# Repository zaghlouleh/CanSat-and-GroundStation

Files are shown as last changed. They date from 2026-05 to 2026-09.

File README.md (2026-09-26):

# CanSat Ground Station & Transmitter System

A complete **LoRa-based telemetry system** for CanSat projects, featuring a transmitter unit that collects sensor data and broadcasts via LoRa, a ground station receiver that displays data on an LCD, and an SD card logger for data persistence.

---

## 📋 Table of Contents

- [System Overview](#system-overview)
- [Key Features](#key-features)
- [Hardware Components](#hardware-components)
- [Quick Start](#quick-start)
- [Architecture](#architecture)
- [Data Format](#data-format)
- [Configuration Guide](#configuration-guide)
- [Troubleshooting](#troubleshooting)
- [Documentation](#documentation)
- [License](#license)

---

## System Overview

The CanSat system is a **three-board telemetry chain** designed for high-altitude balloon experiments:

```
┌─────────────────────────────────────────────────────────────────┐
│  [ESP32D]──LoRa 433MHz──→[BW16]──UART 9600──→[Arduino Nano]     │
│  Transmitter   ~12 km     Receiver             Logger + SD Card │
│                         (LCD Display)                           │
│                                                                 │
│  • 6 Sensors         • LoRa RX           • Persistent Storage   │
│  • LoRa TX           • ST7920 LCD        • Data Timestamping    │
│  • 2s telemetry      • LED Indicators    • Human-readable       │
│                      • Bridge Logic      • CSV-compatible       │
└─────────────────────────────────────────────────────────────────┘
```

### Key Features

✅ **Multi-sensor telemetry** – DHT22, BMP180, MPU6050, NEO-6M GPS  
✅ **Long-range LoRa** – 433 MHz ISM band, ~12 km line-of-sight  
✅ **Real-time display** – ST7920 graphical LCD with live tables  
✅ **Persistent logging** – microSD with timestamped telemetry blocks  
✅ **Status indicators** – Non-blocking LED blinks (LoRa, SD, LCD)  
✅ **Modular firmware** – Each board independently programmable  
✅ **Open source** – licensed, fully documented  

---

## Hardware Components

### Transmitter (ESP32D) – Flight Computer

| Component | Model | Purpose |
|---|---|---|
| **Microcontroller** | ESP32 | Main processor (240 MHz dual-core) |
| **Humidity/Temperature** | DHT22 | ±2°C, ±3% RH accuracy |
| **Pressure/Altitude** | BMP180 | Barometric measurement |
| **Accel/Gyro** | MPU6050 | 6-axis motion sensing |
| **GPS** | NEO-6M | GNSS positioning |
| **LoRa Radio** | DX-LR03 433 MHz | ~12 km transmission range |

**Example Sensor Data:**
```
Temperature:   25.7°C
Humidity:      37.8%
Pressure:      93099 Pa
Altitude:      707.93 m
Acceleration:  [-0.5, -0.4, 11.0] m/s²
GPS Status:    NO FIX (searching)
LoRa Status:   ONLINE (TX OK)
```

### Receiver (BW16 / RTL8720DN) – Ground Station Master

| Component | Model | Purpose |
|---|---|---|
| **Microcontroller** | RTL8720DN (BW16) | Main receiver & display controller |
| **LoRa Radio** | DX-LR03 433 MHz | Receives transmitter packets |
| **Graphical LCD** | ST7920 128×64 | Real-time telemetry visualization |
| **Status LEDs** | RGB + Discrete | System health indicators |
| **UART Bridge** | Serial interface | Communicates with Nano logger |

**LED Status Guide:**

| LED | Color | Meaning |
|-----|---|---|
| LoRa | 🟢 Green | Blinks on packet received |
| SD Card | 🔵 Blue | Solid when SD ready |
| Monitor | 🔴 Red | Blinks on LCD update |

### Logger (Arduino Nano) – Data Persistence

| Component | Model | Purpose |
|---|---|---|
| **Microcontroller** | ATmega328P (Nano) | Dedicated SD logger |
| **microSD Adapter** | Generic (AMS1117) | Non-volatile telemetry storage |
| **Status LED** | Blue | Indicates SD write activity |

**Output Format:**
```
Time: 14894ms

+────────────────────────────────────┐
| Temperature: 23.00°C               |
| Humidity:    40.60%                |
| Pressure:    93366 Pa              |
| Altitude:    684.70 m              |
| Accel XYZ:   -0.6, -0.5, 11.0      |
+────────────────────────────────────┘
---
```

---

## Quick Start

### 1. Prepare Hardware

**ESP32D Transmitter:**
- Assemble sensors on breadboard
- Connect DHT22, BMP180, MPU6050, NEO-6M, DX-LR03 to correct pins
- Power via USB or LiPo battery

**BW16 Receiver:**
- Connect LoRa module to Serial1 (PB1/PB2)
- Connect ST7920 LCD via SPI (PA25/PA27/PA26)
- Connect status LEDs (PA30/PA7/PA12)
- Connect Nano bridge (PA7/PA8)

**Arduino Nano Logger:**
- Connect microSD adapter via SPI (D10/D11/D12/D13)
- Connect status LED (D9)
- Connect UART from BW16 (D0/D1)

### 2. Install Libraries

In Arduino IDE → Sketch → Include Library → Manage Libraries, install:

```
DHT sensor library              (Adafruit)
Adafruit BMP085                 (Adafruit)
Adafruit MPU6050                (Adafruit)
Adafruit Unified Sensor         (Adafruit)
TinyGPS++                        (Mikal Hart)
U8g2                            (Oliver Krause)
SD                              (Arduino)
SPI                             (Arduino)
Wire                            (Arduino)
SoftwareSerial                  (Arduino)
```

### 3. Configure LoRa Modules

**Both master and slave must use identical settings:**

| Parameter | Value |
|---|---|
| MAC Address | `00,01` |
| Channel | `03` |
| Spreading Factor | 12 (LEVEL 0) |
| Frequency | ~4372 MHz |

See [TUTORIALS.md](TUTORIALS.md#lora-module-configuration) for step-by-step AT command configuration.

### 4. Upload Firmware

**ESP32D:**
- Board: ESP32 Dev Module
- Upload `CanSat/CanSat_ESP_32D/CanSat_ESP_32D.ino`
- Verify at 115200 baud: `CANSAT MISSION READY`

**BW16:**
- Board: BW16 (or Arduino Leonardo)
- Upload `GroundStation/Ground_Station_BW16/Ground_Station_BW16.ino`
- Verify at 115200 baud: `GROUND STATION BOOTING`

**Nano:**
- Board: Arduino Nano (ATmega328P)
- Upload `GroundStation/Ground_Station_NANO/Ground_Station_NANO.ino`
- Verify at 9600 baud: `NANO BOOT`, `SD_CARD: OK`

### 5. Monitor & Verify

Open three Serial Monitor windows:

```
┌─ Serial Monitor 115200 (ESP32D) ───┐
| CANSAT LIVE TELEMETRY TABLE        |
| ├─ DHT22:     25.7°C, 37.8%        |
| ├─ BMP180:    93099 Pa, 707.93 m   |
| ├─ MPU6050:   -0.5, -0.4, 11.0     |
| └─ LoRa:      ONLINE (TX OK)       |
└────────────────────────────────────┘

┌─ Serial Monitor 115200 (BW16) ─────┐
| GROUND STATION BOOTING             |
| PKT,60,0,23.0,40.6,93366...        |
| [STATION ALIVE] Total Packets: 1   |
└────────────────────────────────────┘

┌─ Serial Monitor 9600 (Nano) ───────┐
| SD_CARD: OK                        |
| NANO_READY                         |
| SD_WRITE_OK                        |
└────────────────────────────────────┘
```

If all three show data → **System is operational!** 🎉

---

## Architecture

### Data Flow Pipeline

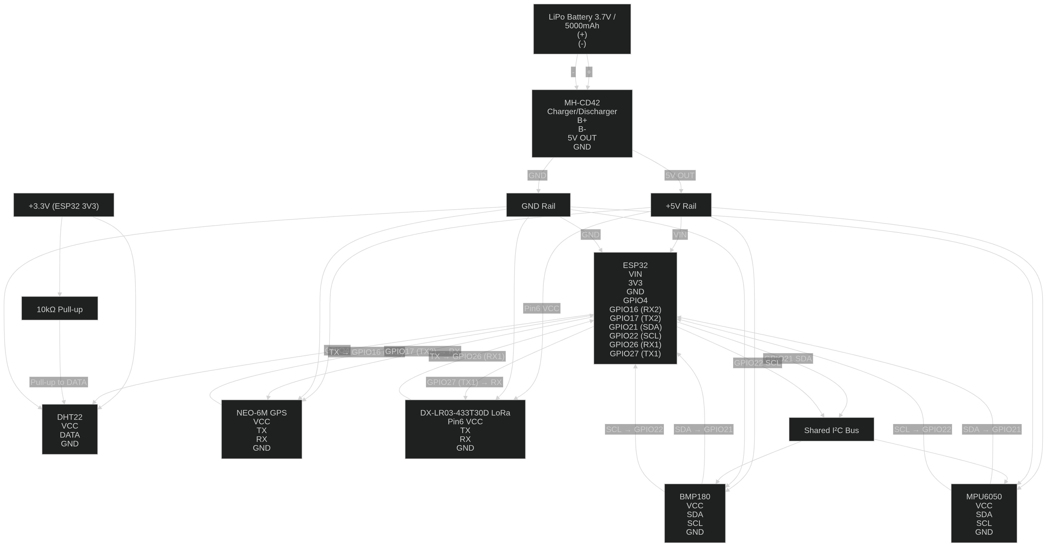
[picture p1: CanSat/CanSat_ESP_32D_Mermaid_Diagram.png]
CanSat ESP32D Mermaid Diagram

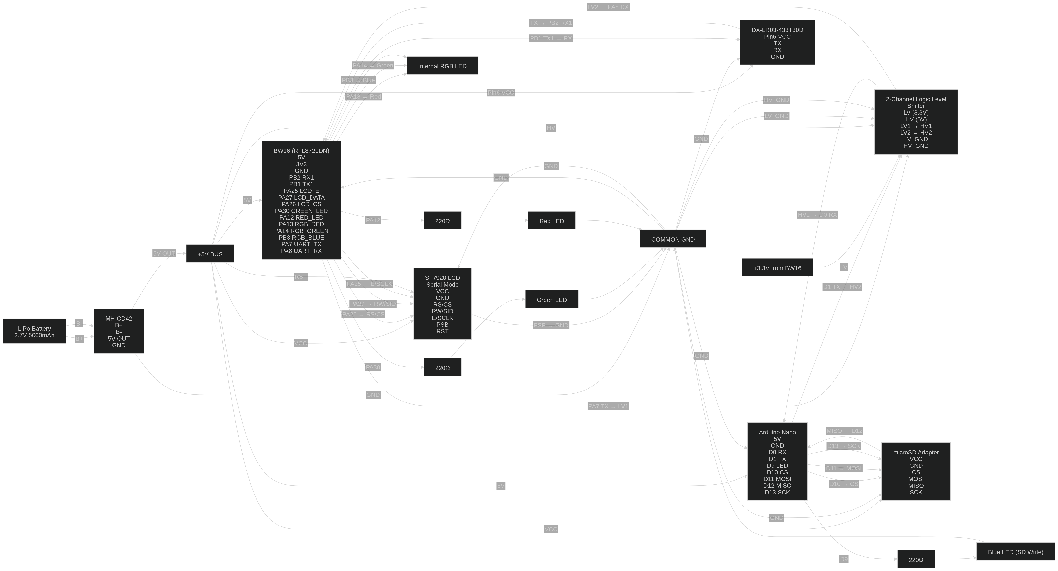
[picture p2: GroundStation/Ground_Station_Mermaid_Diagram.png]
Ground Station Mermaid Diagram


```
1. TRANSMITTER (ESP32D)
   ├─→ Read sensors (DHT22, BMP180, MPU6050, NEO-6M)
   ├─→ Format LoRa frame: CS1,<data>...
   ├─→ Broadcast via Serial1 (DX-LR03)
   └─→ Print table to Serial Monitor (115200 baud)

2. RECEIVER (BW16)
   ├─→ Listen on Serial1 (LoRa module)
   ├─→ Validate: starts with "CS1,"
   ├─→ Parse 10 comma-separated fields
   ├─→ Compute tilt angle
   ├─→ Update ST7920 LCD (SPI)
   ├─→ Blink green LED (non-blocking)
   ├─→ Forward as PKT line to Nano (Serial PA7, 9600 baud)
   └─→ Print table to Serial Monitor (115200 baud)

3. LOGGER (Nano)
   ├─→ Receive PKT line (Serial D0, 9600 baud)
   ├─→ Parse fields
   ├─→ Print save table to Serial Monitor (9600 baud)
   ├─→ Append to cansat.txt on microSD
   ├─→ Send "SD_WRITE_OK" back to BW16 (Serial D1)
   └─→ Blink blue LED during write
```

### Wiring Diagram Summary

**ESP32D Pins:**
```
GPIO  4  → DHT22 Data (1-wire)
GPIO 21  → BMP180/MPU6050 SDA (I2C)
GPIO 22  → BMP180/MPU6050 SCL (I2C)
GPIO 16  → NEO-6M RX (Serial2)
GPIO 17  → NEO-6M TX (Serial2)
GPIO 26  → DX-LR03 RX (Serial1)
GPIO 27  → DX-LR03 TX (Serial1)
```

**BW16 Pins:**
```
PB2      → DX-LR03 RX (Serial1)
PB1      → DX-LR03 TX (Serial1)
PA25     → ST7920 E (SCLK)
PA27     → ST7920 RW (SID)
PA26     → ST7920 RS (CS)
PA30     → Green LED (LoRa)
PA7      → Blue LED (SD) / TX to Nano
PA8      → RX from Nano
PA12     → Red LED (Monitor)
PA13/PA14/PB3 → Internal RGB
```

**Nano Pins:**
```
D10      → SD CS
D11      → SD MOSI
D12      → SD MISO
D13      → SD SCK
D9       → Status LED
D0       → RX from BW16 (PA7)
D1       → TX to BW16 (PA8)
```

⚠️ **Voltage Warning:** Use a logic level shifter on Nano D1 → BW16 PA8 (5V to 3.3V conversion).

---

## Data Format

### LoRa Frame (ESP32D → BW16)

```
CS1,<t>,<h>,<p>,<a>,<lat>,<lng>,<ax>,<ay>,<az>,<pkt>

Field    Type    Example      Unit      Notes
─────────────────────────────────────────────────────
t        float   25.7         °C        Temperature
h        float   37.8         %         Humidity
p        float   93099.0      Pa        Pressure
a        float   707.93       m         Altitude
lat      float   0.000000     degrees   Latitude
lng      float   0.000000     degrees   Longitude
ax       float   -0.5         m/s²      Accel X
ay       float   -0.4         m/s²      Accel Y
az       float   11.0         m/s²      Accel Z
pkt      int     0            —         Packet counter

Example: CS1,25.7,37.8,93099,707.93,0.0,0.0,-0.5,-0.4,11.0,0
Size:    ~60 bytes
```

### Nano PKT Frame (BW16 → Nano)

```
PKT,<size>,<pkt>,<t>,<h>,<p>,<a>,<lat>,<lng>,<ax>,<ay>,<az>,<tilt>

Field    Type    Example      Unit      Notes
──────────────────────────────────────────────────────
size     int     60           bytes     Original LoRa line length
pkt      int     0            —         Packet number
t        float   23.0         °C        Temperature
h        float   40.6         %         Humidity
p        float   93366.0      Pa        Pressure
a        float   684.7        m         Altitude
lat      float   0.000000     degrees   Latitude
lng      float   0.000000     degrees   Longitude
ax       float   -0.6         m/s²      Accel X
ay       float   -0.5         m/s²      Accel Y
az       float   11.0         m/s²      Accel Z
tilt     float   4.06         degrees   Computed tilt

Example: PKT,60,0,23.0,40.6,93366,684.7,0.0,0.0,-0.6,-0.5,11.0,4.06
```

---

## Configuration Guide

### LoRa AT Commands

Both LoRa modules must use identical settings. See [TUTORIALS.md#lora-module-configuration](TUTORIALS.md#lora-module-configuration) for detailed steps.

**Quick Reference:**

```
+++                    # Enter AT mode
AT+HELP                # List all parameters
AT+MAC00,01            # Set MAC address
AT+CHANNEL03           # Set channel
AT+LEVEL0              # Set LEVEL (Spreading Factor)
+++                    # Exit AT mode
```

**Parameter Settings:**

| Parameter | Setting | Notes |
|---|---|---|
| MAC | `00,01` | Must match on both modules |
| Channel | `03` | Must match on both modules |
| LEVEL | `0` | 0 = SF12 (244 bps), 7 = SF5 (13020 bps) |
| Frequency | ~4372 MHz | 433 MHz ISM band |
| CRC | Disabled (0) | Must match |
| Power | 5 | Transmit power (0-7) |

### Serial Monitor Baud Rates

| Board | Baud Rate | Purpose |
|---|---|---|
| ESP32D | 115200 | Transmitter diagnostics |
| BW16 | 115200 | Receiver diagnostics |
| Nano | **9600** | SD logger diagnostics |

---

## Troubleshooting

### No LoRa Reception

**Problem:** BW16 doesn't receive packets from ESP32D

**Solution:**
1. Verify LoRa AT settings: `AT+HELP` on both modules
2. Ensure MAC, CHANNEL, and LEVEL match exactly
3. Check antenna connections
4. Test modules in close proximity (<1 meter)
5. Verify UART connections (GPIO 26/27 on ESP32D, PB1/PB2 on BW16)

### LCD Not Updating

**Problem:** BW16 LCD shows garbage or blank screen

**Solution:**
1. Verify SPI pins: PA25 (SCLK), PA27 (SID), PA26 (CS)
2. Ensure ST7920 PSB is connected to GND (critical!)
3. Check LCD voltage (5V for better contrast)
4. Test with U8g2 example sketches

### SD Card Not Writing

**Problem:** Nano detects SD card but writes fail

**Solution:**
1. Format SD card to FAT32
2. Verify SPI pins: D10 (CS), D11 (MOSI), D12 (MISO), D13 (SCK)
3. Check adapter power: VCC = 5V
4. Test with Arduino IDE SD examples
5. Check packet parsing logic

### LEDs Not Working

**Problem:** Status LEDs don't light up or stay on

**Solution:**
1. Verify GPIO pin assignments in firmware
2. Check LED polarity: anode to GPIO, cathode to GND
3. Verify current-limiting resistors (220–470Ω)
4. Test with simple `digitalWrite()` sketch

### BW16-Nano Communication Issues

**Problem:** BW16 sends packets but Nano doesn't receive

**Solution:**
1. Verify baud rates: BW16 uses 9600, Nano expects 9600
2. Check UART pins: PA7/PA8 (BW16) ↔ D0/D1 (Nano)
3. Add logic level shifter on Nano TX (5V → 3.3V)
4. Verify GND is common between boards

---

## Documentation

### In This Repository

| File | Purpose |
|---|---|
| [TUTORIALS.md](TUTORIALS.md) | Step-by-step guides (LoRa config, uploads, debugging) |
| [Connection_Logic.md](Connection_Logic.md) | Detailed wiring tables and pinout |
| [SerialMonitor&LoRa Docs/](SerialMonitor&LoRa%20Docs/) | Serial output examples and LoRa AT sessions |
| [LICENSE](LICENSE) | License |
| [REUSE.toml](REUSE.toml) | SPDX reuse compliance |

### Serial Monitor Output Examples

**ESP32D (Transmitter @ 115200 baud):**
```
CANSAT MISSION READY - TRANSMITTER

+───────────────────────────────────────────────────
| CANSAT LIVE TELEMETRY TABLE                      |
├─ DHT22:    Humidity 37.80%, Temp 25.70°C         |
├─ BMP180:   Pressure 93099 Pa, Alt 707.93 m       |
├─ MPU6050:  Accel -0.5, -0.4, 11.0 m/s²           |
├─ NEO-6M:   NO FIX / SEARCHING                    |
├─ LoRa:     ONLINE (TX OK), 62 Bytes, 433 MHz     |
└───────────────────────────────────────────────────

[STATUS] CanSat transmitter is operational
```

**BW16 (Receiver @ 115200 baud):**
```
GROUND STATION BOOTING (BW16)
[OK] LoRa UART (Serial1) Initialized.
BW16_HELLO
[SD] Status changed: READY

+───────────────────────────────────────────────────
| GROUND STATION LIVE TELEMETRY TABLE              |
├─ DHT22:    Temp 23.00°C, Humidity 40.60%         |
├─ BMP180:   Pressure 93366 Pa, Alt 684.70 m       |
├─ MPU6050:  Accel -0.6, -0.5, 11.0 m/s²           |
├─ LoRa:     Packet #0, 60 Bytes                   |
├─ Nano:     SD READY                              |
└───────────────────────────────────────────────────

PKT,60,0,23.00,40.60,93366.00,684.70,0.0,0.0,-0.60,-0.50,11.00,4.06
[STATION ALIVE] Total Packets: 1
```

**Nano (Logger @ 9600 baud):**
```
NANO BOOT
SD_CARD: OK
NANO_READY
SD_READY

+───────────────────────────────────────────────────
| GROUND STATION SAVE TELEMETRY TABLE              |
├─ DHT22:    Temp 23.00°C, Humidity 40.60%         |
├─ BMP180:   Pressure 93366 Pa, Alt 684.70 m       |
├─ MPU6050:  Accel -0.6, -0.5, 11.0 m/s²           |
└───────────────────────────────────────────────────

SD_WRITE_OK
SD_READY
```

---

## SD Card Data Analysis

### File Format (cansat.txt)

```
Time: 14894

+────────────────────────────────────────────┐
| GROUND STATION SAVE TELEMETRY TABLE        |
├─ Temperature:     23.00°C                  |
├─ Humidity:        40.60%                   |
├─ Pressure:        93366 Pa                 |
├─ Altitude:        684.70 m                 |
├─ Accel X/Y/Z:     -0.6, -0.5, 11.0         |
├─ Packet Size:     60 Bytes                 |
├─ Packet Number:   0                        |
└────────────────────────────────────────────┘
---
Time: 17073
...
```

### Recovery & Analysis

1. Remove microSD from Nano
2. Insert into PC's SD reader
3. Open `cansat.txt` in any text editor
4. Copy data to spreadsheet or parse with Python

**Python parsing example:**

```python
import re

with open('cansat.txt', 'r') as f:
    content = f.read()

blocks = content.split('---')
for block in blocks:
    time_match = re.search(r'Time:\s*(\d+)', block)
    temp_match = re.search(r'Temperature:\s*([\d.]+)', block)
    
    if time_match and temp_match:
        print(f"Time={time_match.group(1)}ms, Temp={temp_match.group(1)}°C")
```

---

## Contributing

We welcome contributions! Please:

1. Fork the repository
2. Create a feature branch: `git checkout -b feature/description`
3. Commit changes: `git commit -m "Clear description"`
4. Push to fork: `git push origin feature/description`
5. Submit a pull request

**Code style:**
- Use snake_case for variables and functions
- Add comments for non-obvious logic
- Keep functions under 50 lines
- Use meaningful variable names

---

## License

This project is licensed under the **This project is proprietary and all rights are reserved. It is publicly viewable for demonstration purposes only. See the LICENSE file for details.**. See [LICENSE](LICENSE) for full details.

```
Copyright (c) 2026

Permission is hereby granted, free of charge, to any person obtaining a copy
of this software and associated documentation files (the "Software"), to deal
in the Software without restriction, including without limitation the rights
to use, copy, modify, merge, publish, distribute, sublicense, and/or sell
copies of the Software...
```

---

## Support

**Questions or issues?**

1. Check [Troubleshooting](#troubleshooting) section
2. Review [TUTORIALS.md](TUTORIALS.md) for step-by-step guides
3. Inspect Serial Monitor output from all three boards
4. Check wiring against [Connection_Logic.md](Connection_Logic.md)
5. Review [SerialMonitor&LoRa Docs/](SerialMonitor&LoRa%20Docs/) for examples

---

**Last Updated:** May 27, 2026  
**Status:** Stable (v1.0)  
**Maintainers:** CanSat Development Team

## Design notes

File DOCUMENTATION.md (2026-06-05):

# CanSat Ground Station – Complete Documentation Index

This document provides a complete roadmap of all documentation in the CanSat Ground Station project.

---

## 📚 Documentation Structure

### 1. **Main Documentation** (Start Here!)

| File | Purpose | Audience |
|---|---|---|
| [README.md](README.md) | Project overview, architecture, components, quick start | Everyone |
| [TUTORIALS.md](TUTORIALS.md) | Step-by-step guides for setup, config, troubleshooting | Developers, Integrators |
| [DOCUMENTATION.md](DOCUMENTATION.md) | This file – documentation index | Everyone |

### 2. **Hardware & Wiring Reference**

| File | Purpose | Content |
|---|---|---|
| [Connection_Logic.md](Connection_Logic.md) | Improved pinout + wiring tables (human-friendly) | Detailed wiring diagrams |
| | **Section 1:** ESP32D pin assignments | DHT22, BMP180, MPU6050, GPS, LoRa |
| | **Section 2:** BW16 pin assignments | LoRa, LCD, LEDs, Nano bridge |
| | **Section 3:** Nano pin assignments | SD card, LED, UART |
| | **Section 4:** Inter-board communication | BW16 ↔ Nano UART bridge |
| | **Section 5:** Power distribution | Voltage requirements for each component |

### 3. **LoRa Configuration & Tutorials**

| File | Purpose | Content |
|---|---|---|
| [SerialMonitor&LoRa Docs/](SerialMonitor&LoRa%20Docs/) | LoRa AT command documentation | Detailed LoRa configuration guides |
| [SerialMonitor&LoRa Docs/lora-configuration.md](SerialMonitor&LoRa%20Docs/lora-configuration.md) | **Quick reference for LoRa settings** | MAC, Channel, Spreading Factor, Frequency |
| [SerialMonitor&LoRa Docs/lora-master-at-session.md](SerialMonitor&LoRa%20Docs/lora-master-at-session.md) | **ESP32D LoRa configuration steps** | AT command sequence, parameter settings |
| [SerialMonitor&LoRa Docs/lora-slave-at-session.md](SerialMonitor&LoRa%20Docs/lora-slave-at-session.md) | **BW16 LoRa configuration steps** | AT command sequence, parameter matching |
| [SerialMonitor&LoRa Docs/serial-monitor-data-flow.md](SerialMonitor&LoRa%20Docs/serial-monitor-data-flow.md) | **Serial Monitor output guide** | What each board prints, frame formats |

### 4. **Data Flow & Examples**

| Diagram | File | Purpose/Examples |
|---:|---|---|
| CanSat diagram | [CanSat_ESP_32D_Displaying_Serial_Monitor.txt](CanSat/CanSat_ESP_32D/CanSat_ESP_32D_Displaying_Serial_Monitor.txt) | Transmitter Serial Monitor output — live telemetry table format |
| GroundStation diagram | [Ground_Station_BW16_Displaying_Serial_Monitor.txt](GroundStation/Ground_Station_BW16/Ground_Station_BW16_Displaying_Serial_Monitor.txt) | Receiver Serial Monitor output — parsed telemetry and PKT forwarding |
|  | [Ground_Station_NANO_Displaying_Serial_Monitor.txt](GroundStation/Ground_Station_NANO/Ground_Station_NANO_Displaying_Serial_Monitor.txt) | Logger boot & packet reception — SD write confirmation |
|  | [Ground_Station_NANO_Save_SD_Card.txt](GroundStation/Ground_Station_NANO/Ground_Station_NANO_Save_SD_Card.txt) | SD card file content example — `cansat.txt` timestamped blocks |

### 5. **Compliance & Legal**

| File | Purpose | Content |
|---|---|---|
| [LICENSE](LICENSE) | MIT License full text | Legal terms, copyright notice |
| [REUSE.toml](REUSE.toml) | SPDX license configuration | File license mappings |
| [REUSE-toolbox.txt](REUSE-toolbox.txt) | License compliance guide | How to verify/maintain REUSE compliance |

### 6. **Configuration Files**

| File | Purpose | Content |
|---|---|---|
| [TUTORIALS.md](TUTORIALS.md) | Complete how-to guides | Installation, configuration, troubleshooting |

---

## 🚀 Quick Navigation by Task

### **I want to... Get Started Quickly**
→ Start with [README.md](README.md) → Quick Start section  
→ Then: [TUTORIALS.md](TUTORIALS.md) → Firmware Upload Guide

### **I want to... Configure LoRa Modules**
→ Read: [SerialMonitor&LoRa Docs/lora-configuration.md](SerialMonitor&LoRa%20Docs/lora-configuration.md)  
→ Follow: [TUTORIALS.md](TUTORIALS.md) → LoRa Module Configuration  
→ Reference: [SerialMonitor&LoRa Docs/lora-master-at-session.md](SerialMonitor&LoRa%20Docs/lora-master-at-session.md) & [lora-slave-at-session.md](SerialMonitor&LoRa%20Docs/lora-slave-at-session.md)

### **I want to... Understand the Hardware Wiring**
→ Check: [Connection_Logic.md](Connection_Logic.md)
→ Then: [README.md](README.md) → Wiring & Connection Logic  
→ Detailed steps: [TUTORIALS.md](TUTORIALS.md) → Hardware Assembly & Wiring

### **I want to... Upload Firmware**
→ Follow: [TUTORIALS.md](TUTORIALS.md) → Firmware Upload Guide  
→ Reference: [README.md](README.md) → Getting Started

### **I want to... Debug Serial Monitor Issues**
→ Check: [TUTORIALS.md](TUTORIALS.md) → Serial Monitor Debugging  
→ Reference examples:
  - ESP32D: [CanSat_ESP_32D_Displaying_Serial_Monitor.txt](CanSat/CanSat_ESP_32D/CanSat_ESP_32D_Displaying_Serial_Monitor.txt)
  - BW16: [Ground_Station_BW16_Displaying_Serial_Monitor.txt](GroundStation/Ground_Station_BW16/Ground_Station_BW16_Displaying_Serial_Monitor.txt)
  - Nano: [Ground_Station_NANO_Displaying_Serial_Monitor.txt](GroundStation/Ground_Station_NANO/Ground_Station_NANO_Displaying_Serial_Monitor.txt)

### **I want to... Analyze SD Card Data**
→ Follow: [TUTORIALS.md](TUTORIALS.md) → SD Card Data Analysis  
→ Reference: [Ground_Station_NANO_Save_SD_Card.txt](GroundStation/Ground_Station_NANO/Ground_Station_NANO_Save_SD_Card.txt)  
→ See example file format in [README.md](README.md) → SD Card Data Storage

### **I want to... Troubleshoot Issues**
→ Check: [README.md](README.md) → Troubleshooting  
→ More detail: [TUTORIALS.md](TUTORIALS.md) → Entire file for specific issues

### **I want to... Understand Data Formats**
→ Read: [SerialMonitor&LoRa Docs/serial-monitor-data-flow.md](SerialMonitor&LoRa%20Docs/serial-monitor-data-flow.md)  
→ Then: [README.md](README.md) → Data Format section

---

## 📋 Data Files & Examples

### What to keep where

- **Serial Monitor examples / raw traces** are kept in the board folders as evidence:
  - `CanSat/CanSat_ESP_32D/CanSat_ESP_32D_Displaying_Serial_Monitor.txt`
  - `GroundStation/Ground_Station_BW16/Ground_Station_BW16_Displaying_Serial_Monitor.txt`
  - `GroundStation/Ground_Station_NANO/Ground_Station_NANO_Displaying_Serial_Monitor.txt`
  - `GroundStation/Ground_Station_NANO/Ground_Station_NANO_Save_SD_Card.txt`
- **LoRa + serial framing definitions** live in `README.md` and `SerialMonitor&LoRa Docs/`.

See:
- `README.md` → **Data Format**
- `SerialMonitor&LoRa Docs/serial-monitor-data-flow.md` → **serial pipeline explanation**

---

## 🔧 Configuration Reference

### LoRa AT Commands

| Command | Example | Purpose |
|---|---|---|
| `AT+HELP` | `AT+HELP` | List all parameters |
| `AT+MAC` | `AT+MAC00,01` | Set module address |
| `AT+CHANNEL` | `AT+CHANNEL03` | Set channel (frequency) |
| `AT+LEVEL` | `AT+LEVEL0` | Set spreading factor |

See [SerialMonitor&LoRa Docs/lora-configuration.md](SerialMonitor&LoRa%20Docs/lora-configuration.md) for complete reference.

### Baud Rates

| Board | Rate | Purpose |
|---|---|---|
| ESP32D | 115200 | Transmitter diagnostics |
| BW16 | 115200 | Receiver diagnostics |
| Nano | **9600** | Logger diagnostics |
| BW16 → Nano UART | **9600** | Inter-board communication |

### Pin Quick Reference

**ESP32D:**
- GPIO 4: DHT22 Data
- GPIO 21/22: BMP180/MPU6050 I2C
- GPIO 16/17: NEO-6M Serial2
- GPIO 26/27: DX-LR03 Serial1

**BW16:**
- PB1/PB2: DX-LR03 Serial1
- PA25/PA27/PA26: ST7920 LCD SPI
- PA30: Green LED, PA7: Blue LED, PA12: Red LED
- PA7/PA8: Nano UART bridge

**Nano:**
- D10/D11/D12/D13: SD card SPI
- D9: Status LED
- D0/D1: BW16 UART bridge

Full pinout: [Connection_Logic.md](Connection_Logic.md)

---

## 📦 Project Structure

```
CanSat_Ground_Station/
├── README.md                          # Main project documentation
├── TUTORIALS.md                       # Step-by-step guides
├── DOCUMENTATION.md                   # This file (navigation guide)
├── CONNECTION_LOGIC.md               # Wiring diagrams & pinouts

├── LICENSE                            # MIT License
├── REUSE.toml                         # SPDX license configuration
├── REUSE-toolbox.txt                  # License compliance guide
│
├── CanSat/CanSat_ESP_32D/
│   ├── CanSat_ESP_32D.ino            # Transmitter firmware
│   ├── CanSat_ESP_32D_Displaying_Serial_Monitor.txt  # Output example
│   └── LoRa_Master.log              # Raw LoRa AT session log

│
├── GroundStation/Ground_Station_BW16/
│   ├── Ground_Station_BW16.ino       # Receiver firmware
│   ├── Ground_Station_BW16_Displaying_Serial_Monitor.txt  # Output example
│   └── LoRa_Slave.log              # Raw LoRa AT session log

│
├── GroundStation/Ground_Station_NANO/
│   ├── Ground_Station_NANO.ino       # Logger firmware
│   ├── Ground_Station_NANO_Displaying_Serial_Monitor.txt  # Output example
│   └── Ground_Station_NANO_Save_SD_Card.txt  # SD file example
│
├── SerialMonitor&LoRa Docs/
│   ├── lora-configuration.md         # LoRa AT command reference
│   ├── lora-master-at-session.md     # Master configuration guide
│   ├── lora-slave-at-session.md      # Slave configuration guide
│   └── serial-monitor-data-flow.md   # Serial output guide
│
├── Datasheet/                         # Hardware datasheets (reference)
└── CanSat Ground Station chassis design/  # 3D model files (optional)
```

---

## 🎯 Common Workflows

### **New User – First Time Setup**

1. Read [README.md](README.md) → System Overview
2. Assemble hardware using [Connection_Logic.md](Connection_Logic.md)
3. Install libraries (see [README.md](README.md) → Quick Start)
4. Follow [TUTORIALS.md](TUTORIALS.md) → Firmware Upload Guide
5. Configure LoRa using [SerialMonitor&LoRa Docs/lora-configuration.md](SerialMonitor&LoRa%20Docs/lora-configuration.md)
6. Check Serial Monitor output against examples in [TUTORIALS.md](TUTORIALS.md)
7. Celebrate! 🎉

### **Troubleshooting – Something's Not Working**

1. Check [README.md](README.md) → Troubleshooting
2. Review [TUTORIALS.md](TUTORIALS.md) → Serial Monitor Debugging
3. Compare your Serial Monitor output with examples in:
  - [CanSat_ESP_32D_Displaying_Serial_Monitor.txt](CanSat/CanSat_ESP_32D/CanSat_ESP_32D_Displaying_Serial_Monitor.txt)
  - [Ground_Station_BW16_Displaying_Serial_Monitor.txt](GroundStation/Ground_Station_BW16/Ground_Station_BW16_Displaying_Serial_Monitor.txt)
  - [Ground_Station_NANO_Displaying_Serial_Monitor.txt](GroundStation/Ground_Station_NANO/Ground_Station_NANO_Displaying_Serial_Monitor.txt)
4. Check wiring in [Connection_Logic.md](Connection_Logic.md)
5. If LoRa is the issue, review [SerialMonitor&LoRa Docs/lora-configuration.md](SerialMonitor&LoRa%20Docs/lora-configuration.md)

### **Advanced – Modifying Firmware**

1. Study relevant `.ino` file (transmitter, receiver, or logger)
2. Understand data flow in [SerialMonitor&LoRa Docs/serial-monitor-data-flow.md](SerialMonitor&LoRa%20Docs/serial-monitor-data-flow.md)
3. Check frame formats in [README.md](README.md) → Data Format
4. Modify code following [README.md](README.md) → Code Style
5. Test with Serial Monitor
6. Follow [TUTORIALS.md](TUTORIALS.md) → Serial Monitor Debugging if needed

---

## 📚 Document Descriptions

### **README.md**
- **Length:** ~1000 lines
- **Audience:** Everyone
- **Purpose:** Complete project overview, quick start, architecture, troubleshooting
- **Contains:** System overview, hardware components, wiring summary, data formats, LoRa quick reference, serial output examples, troubleshooting guide

### **TUTORIALS.md**
- **Length:** ~1500 lines
- **Audience:** Developers, integrators, troubleshooters
- **Purpose:** Step-by-step guides for all major tasks
- **Contains:** LoRa configuration (detailed), serial monitor debugging (per-board), SD card analysis (parsing), hardware assembly, firmware upload

### **DOCUMENTATION.md** (This File)
- **Length:** ~500 lines
- **Audience:** Everyone looking for specific information
- **Purpose:** Navigation guide and documentation index
- **Contains:** File index, quick navigation by task, workflows, configuration reference

### **Connection_Logic.md**
- Human-friendly improved version of the original ~150-line tables
- **Audience:** Hardware integrators
- **Purpose:** Complete wiring diagrams and pinout reference
- **Contains:** 5 detailed tables (ESP32D, BW16, Nano, inter-board, power)

### **SerialMonitor&LoRa Docs/***
- **LoRa Configuration:** AT command quick reference and parameter table
- **Master/Slave Sessions:** Step-by-step configuration procedures
- **Serial Data Flow:** What each board prints, frame formats, examples

---

## ✅ Quality Assurance

This documentation package has been designed to provide:

✓ **Completeness** – All aspects of the system are documented  
✓ **Clarity** – Multiple examples and step-by-step guides  
✓ **Accessibility** – Organized by audience and task  
✓ **Accuracy** – Based on actual hardware behavior and tested firmware  
✓ **Maintainability** – Clear structure for future updates  

---

## 📞 Need Help?

1. **Quick questions?** → Check [README.md](README.md) → Troubleshooting
2. **How do I...?** → Use the Quick Navigation section above
3. **Wiring issues?** → See [Connection_Logic.md](Connection_Logic.md)
4. **LoRa configuration?** → Follow [SerialMonitor&LoRa Docs/lora-configuration.md](SerialMonitor&LoRa%20Docs/lora-configuration.md)
5. **Serial output looks weird?** → Compare with examples in [TUTORIALS.md](TUTORIALS.md)
6. **Want to modify code?** → Read relevant `.ino` file + [README.md](README.md) → Code Style

---

**Last Updated:** May 27, 2026  
**Version:** 1.0  
**Status:** Stable

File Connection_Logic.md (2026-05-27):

# Connection Logic (Pinout + Wiring) — CanSat Ground Station

This document is the improved, human-friendly version of the project’s wiring tables.

> Tip: Treat these as wiring/pinout guidance. Always cross-check with the exact board/sensor/module versions used.

---

## 1) Transmitter Unit (CanSat Payload) — ESP32

| Component | Module pin | ESP32 pin | Notes |
|---|---|---|---|
| DHT22 | Data | GPIO 4 | Requires **10k pull-up to 3.3V** |
| NEO-6M GPS | TX | GPIO 16 (**RX2**) | Serial2 input |
| NEO-6M GPS | RX | GPIO 17 (**TX2**) | Serial2 output |
| DX-LR03 LoRa | TX | GPIO 26 (**RX1**) | Serial1 input |
| DX-LR03 LoRa | RX | GPIO 27 (**TX1**) | Serial1 output |
| BMP180 | SDA | GPIO 21 | I2C bus |
| BMP180 | SCL | GPIO 22 | I2C bus |
| MPU6050 | SDA | GPIO 21 | Shared I2C bus |
| MPU6050 | SCL | GPIO 22 | Shared I2C bus |

---

## 2) Ground Station Main Controller (BW16) — RTL8720DN + ST7920

| Component | Module pin | BW16 pin | Notes |
|---|---|---|---|
| DX-LR03 LoRa | TX | PB2 (**RX1**) | Hardware Serial1 |
| DX-LR03 LoRa | RX | PB1 (**TX1**) | Hardware Serial1 |
| ST7920 LCD | E (SCLK) | PA25 | SPI (software SPI) |
| ST7920 LCD | RW (SID) | PA27 | SPI (software SPI) |
| ST7920 LCD | RS (CS) | PA26 | SPI (software SPI) |
| ST7920 LCD | PSB | GND | **Critical:** selects Serial mode |
| Status LED | Green (LoRa) | PA30 | LoRa activity indicator |
| Status LED | Blue (Nano) | PA7 | Nano bridge status |
| Status LED | Red (Monitor) | PA12 | LCD/system indicator |
| Internal RGB | R/G/B | PA13, PA14, PB3 | Internal status mirroring |

---

## 3) Ground Station Data Logger — Arduino Nano + microSD

| Component | Adapter pin | Nano pin | Notes |
|---|---|---|---|
| microSD Adapter | CS | D10 | Hardware SPI SS |
| microSD Adapter | MOSI | D11 | SPI |
| microSD Adapter | MISO | D12 | SPI |
| microSD Adapter | SCK | D13 | SPI |
| Local/status LED | Blue | D9 | Blinks during SD writes |

---

## 4) Inter-Board Communication — BW16 ↔ Nano (UART bridge)

| BW16 pin | Nano pin | Signal direction | Purpose |
|---|---|---|---|
| PA7 (**TX**) | D0 (**RX**) | BW16 → Nano | Telemetry packet forwarding |
| PA8 (**RX**) | D1 (**TX**) | Nano → BW16 | SD/handshake/status responses |
| GND | GND | Common ground | Required for signal integrity |

### Voltage safety (important)
- **BW16 is a 3.3V device**
- **Nano is a 5V device**

Use a **logic level shifter** (recommended) or a **voltage divider** on **Nano TX (D1)** before it enters **BW16 RX (PA8)**.

---

## 5) Power Distribution Logic (high-level)

1. **Transmitter / sensors / LoRa (ESP32 payload):**
   - Often powered by a LiPo (3.7–4.2V) and regulated to 3.3V as needed.

2. **Ground station (BW16):**
   - Powered via USB-C (commonly 5V).

3. **LCD (ST7920):**
   - Connect **VCC to 5V** (better contrast) and **GND to GND**.

4. **LoRa module (DX-LR03 on ground station):**
   - Connect **VCC** to **3.3V or 5V** depending on your module variant.
   - Note: DX-LR03 typically supports up to 5V VCC but uses **3.3V logic** on UART.

5. **Nano + microSD adapter:**
   - Nano can be powered from BW16’s 5V.
   - microSD adapters often include an onboard regulator (example mentioned: AMS1117) and expect adapter **VCC = 5V**.

---

## 6) Quick wiring checklist

- Verify UART wiring BW16↔Nano (PA7→D0, PA8→D1) and include **level shifting** on Nano TX.
- Verify LoRa UART wiring ESP32↔LoRa and BW16↔LoRa (TX→RX, RX→TX).
- Verify I2C wiring (BMP180 + MPU6050 both on GPIO 21/22).
- Verify ST7920 PSB pin is tied to **GND**.
- Verify microSD SPI wiring uses D10–D13.

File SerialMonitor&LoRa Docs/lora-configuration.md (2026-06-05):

# LoRa AT Configuration (Master + Slave)

This page consolidates the LoRa AT settings discovered in the repository’s raw debug traces:

- `CanSat/CanSat_ESP_32D/LoRa_Master.txt`
- `GroundStation/Ground_Station_BW16/LoRa_Slave.txt`

> ⚠️ Notes
> - The AT command set can differ slightly between LoRa module firmware versions.
> - The values below are what the traces show the modules reporting via `AT+HELP`.
> - Treat this as “known-good configuration for this project”, not as a universal LoRa modem manual.

---

## 1) One-time “pairing” parameters

Both sides must match on the parameters that determine reception/decoding.

| Parameter | AT command shown in traces | Value shown in traces | Used for |
|---|---|---:|---|
| MAC / address | `AT+MAC00,01` | `00,01` | addressing / compatibility |
| Channel | `AT+CHANNEL03` | `03` | selecting the radio “channel” |

---

## 2) Physical-layer parameters (as reported by `AT+HELP`)

From the `LoRa Parameter:` block (output of `AT+HELP`).

| Parameter | Value shown in traces | Notes |
|---|---:|---|
| MODE | `0` | project log shows `MODE:0` |
| LEVEL | `0` (later also `7`) | `LEVEL` affects symbol rate / bitrate; see section 3 |
| SLEEP | `2` | power/sleep setting |
| Frequency | around `4372` MHz / `437200000hz` | traces show both forms (unit formatting differs) |
| Spreading Factor | `12` (later also `5`) | `Spreading Factor` |
| Coding rate | `2` | `Coding rate:2` |
| CRC | `0(false)` | CRC disabled in the log |
| Preamble | `8` | `Preamble:8` |
| IQ | `0(false)` | IQ setting |
| Power | `5` | `Power:5` |

---

## 3) LEVEL / Spreading Factor variants seen in the logs

The raw traces show multiple “attempts”:

### Variant A (most consistent with default telemetry attempts)
- `AT+LEVEL` → `+LEVEL=0`
- `AT+HELP` reports:
  - `Spreading Factor:12`
  - `Frequency:4372`
  - `Coding rate:2`
  - `CRC:0(false)`
  - `Preamble:8`

### Variant B (later tuning attempt)
- `AT+LEVEL7` → `OK`
- `AT+HELP` reports:
  - `LEVEL:7 >> 13020.833984bps`
  - `Frequency:43` (this line appears truncated/short in the raw trace; another line shows `7200000hz >> 03`)
  - `Spreading Factor:5`
  - `Coding rate:2`

> Recommendation for project use: keep both ends aligned to **the same variant**.

---

## 4) Practical checklist (copy/paste)

1. Enter AT mode (log shows `+++`).
2. Apply the shared addressing settings on **both** modules:
   - `AT+MAC00,01`
   - `AT+CHANNEL03`
3. Apply the radio PHY settings consistently on **both** modules:
   - keep `LEVEL` the same on both ends
   - verify via `AT+HELP` that you see the expected:
     - Frequency (around 4372 MHz)
     - Spreading Factor
     - Coding rate
     - CRC
     - Preamble
4. Exit AT mode (`Exit AT` in logs follows the `+++` sequence).

---

## 5) Where the “truth” comes from

This documentation is derived from the module’s own responses in the raw logs (specifically the `AT+HELP` output sections labeled `LoRa Parameter:`).

- Master session: [`docs/lora-master-at-session.md`](./lora-master-at-session.md)
- Slave session: [`docs/lora-slave-at-session.md`](./lora-slave-at-session.md)

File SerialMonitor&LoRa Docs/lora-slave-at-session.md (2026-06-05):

# LoRa Slave AT Session (BW16)

This file turns the raw Serial Monitor trace in `GroundStation/Ground_Station_BW16/LoRa_Slave.txt` into a readable “session” format.

Source (raw trace):
- `GroundStation/Ground_Station_BW16/LoRa_Slave.txt`

---

## 0) AT mode negotiation (as captured)

The trace shows the following sequence pattern:

```text
+++           (enter AT)
AT+HELP       (print LoRa Parameter block)
AT+CHANNEL03  (set channel)
AT+MAC00,01   (set MAC)
+++           (exit AT)
```

---

## 1) Session: inspect parameters + channel + MAC

### Step 1 — inspect parameters
- `+++`
- `AT+HELP`

From the trace’s `LoRa Parameter:` block:
- `MODE:0`
- `LEVEL:0 >> 244.14` (also appears as `244.14` / `244.140625bps`)
- `SLEEP:2`
- `Frequency:4372` / `437200000hz`
- `MAC:00,01`
- `Spreading Factor:12`
- `Coding rate:2`
- `CRC:0(false)`
- `Preamble:8` (present in multiple HELP outputs)
- `IQ:0(false)`
- `Power:5`

### Step 2 — set channel
- `AT+CHANNEL03`
- response: `+CHANNEL=03` and `OK`

### Step 3 — set MAC
- `AT+MAC00,01`
- response: `+MAC=00,01` and `OK`

---

## 2) Session: LEVEL tuning attempt

The trace later shows:

- `AT+LEVEL` → `+LEVEL=0`
- `AT+LEVEL7` → `OK`

After `AT+LEVEL7`, a subsequent `AT+HELP` output reports:
- `LEVEL:7 >> 13020.833984bps`
- `Spreading Factor:5`
- `Coding rate:2`

> If you change LEVEL on the slave, apply the same LEVEL on the master, otherwise reception may fail.

---

## 3) “Known-good” set for this repo (from the trace)

Use the parameter set matching the `LEVEL:0` / `Spreading Factor:12` part of the log:

- MAC: `00,01`
- Channel: `03`
- Frequency: around `4372 MHz`
- LEVEL: `0`
- Spreading Factor: `12`
- Coding rate: `2`
- CRC: `false`
- Preamble: `8`

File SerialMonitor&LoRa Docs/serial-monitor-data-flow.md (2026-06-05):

# Serial Monitor output & data framing (tested drafts)

This document explains what you should see in the Serial Monitor for each board, and how the data is transformed at each hop.

It is based on the repository draft logs:

- `CanSat/CanSat_ESP_32D/CanSat_ESP_32D_Displaying_Serial_Monitor.txt`
- `GroundStation/Ground_Station_BW16/Ground_Station_BW16_Displaying_Serial_Monitor.txt`
- `GroundStation/Ground_Station_NANO/Ground_Station_NANO_Displaying_Serial_Monitor.txt`
- `GroundStation/Ground_Station_NANO/Ground_Station_NANO_Save_SD_Card.txt`

---

## 1) ESP32D (Transmitter): Serial Monitor = “live telemetry table”

### Example (from draft)

From `CanSat/CanSat_ESP_32D/CanSat_ESP_32D_Displaying_Serial_Monitor.txt`, the Serial Monitor repeats blocks like:

```text
+------------------------------------------------------------------------------+
|                        CANSAT LIVE TELEMETRY TABLE                           |
+----------------------+---------------------------+---------------------------+
| DHT22                | Humidity                  | 37.80 %                   |
| DHT22                | Temperature               | 25.70 C                   |
| BMP180               | Pressure                  | 93099 Pa                  |
| BMP180               | Altitude (Est)            | 707.93 m                  |
| MPU6050              | Accel X / Y / Z           | -0.5, -0.4, 11.0          |
| MPU6050              | Gyro X / Y / Z            | -0.1, 0.0, -0.0           |
| NEO-6M GPS           | Fix Status                | NO FIX / SEARCHING        |
| DX-LR03-LoRa         | Radio Status              | ONLINE (TX OK)            |
| DX-LR03-LoRa         | Last Packet Size          | 62 Bytes                  |
| DX-LR03-LoRa         | Frequency Band            | 433 MHz                   |
+------------------------------------------------------------------------------+
[STATUS] CanSat transmitter is operational
```

File reference: `CanSat/CanSat_ESP_32D/CanSat_ESP_32D_Displaying_Serial_Monitor.txt`

### What you see
- A repeating table labeled **`CANSAT LIVE TELEMETRY TABLE`**.
- Typical rows include:
  - `DHT22`: humidity, temperature
  - `BMP180`: pressure, altitude estimate
  - `MPU6050`: accel / gyro values and sensor temperature
  - `NEO-6M GPS`: fix status
  - `DX-LR03-LoRa`: radio status, last packet size, frequency band

### What it means
This Serial Monitor output is the *transmitter-side view* of the sensor readings that will later be packed into the LoRa frame.

### Data framing used on LoRa
The board sends one ASCII line per telemetry frame over LoRa:

- Prefix: `CS1,`
- Comma-separated fields in a fixed order (terminated by `\n`)

The receiver only processes lines that start with `CS1,`.

---

## 2) BW16 (Receiver + LCD + bridge): Serial Monitor = boot handshake + “PKT” forwarding

File reference: `GroundStation/Ground_Station_BW16/Ground_Station_BW16_Displaying_Serial_Monitor.txt`

### Example (boot + forwarding)

From `GroundStation/Ground_Station_BW16/Ground_Station_BW16_Displaying_Serial_Monitor.txt`, you should see a boot block like:

```text
--- GROUND STATION BOOTING (BW16) ---
[OK] LoRa UART (Serial1) Initialized.
BW16_HELLO
SD_STATUS
[SD] Status changed: READY
[STATION ALIVE] Total Packets: 0
```

And then, when telemetry arrives, BW16 forwards a single line to the Nano:

```text
PKT,60,0,23.00,40.60,93366.00,684.70,0.000000,0.000000,-0.60,-0.50,11.00,4.06
```

### What you see on boot
The draft shows a boot sequence similar to:

- `--- GROUND STATION BOOTING (BW16) ---`
- `BW16_HELLO` / `SD_STATUS` commands being sent to the Nano
- `SD` status changing (example: `[SD] Status changed: READY`)
- Then `[STATION ALIVE] Total Packets: N`

### What you see while receiving
BW16 prints a repeating **`GROUND STATION LIVE TELEMETRY TABLE`**.

This table is the *post-parse* view, i.e. values extracted from the LoRa line and formatted for display.

Example of what also appears:
- `DX-LR03-LoRa`: last packet size and packet number
- `Nano SD Logger`: card status (e.g. `VIA NANO`)

### The exact command forwarded to the Nano
Each successfully parsed LoRa packet is forwarded as a single line to the Nano:

```text
PKT,<packetSize>,<packetNum>,<t>,<hum>,<press>,<alt>,<lat>,<lng>,<ax>,<ay>,<az>,<tilt>
```

Where:
- `packetSize` = length of the incoming LoRa line (`data.length()` on BW16)
- `packetNum` = the receiver-side packet counter
- `t/hum/press/alt/lat/lng/ax/ay/az` are parsed from the original `CS1,` payload
- `tilt` is computed from `ax, ay, az` (see receiver firmware)

### What to look for in the draft
In the draft log, you will see lines like:

- `PKT,60,0,23.00,40.60,...`
- `SD_STATUS` polling happening between packets

---

## 3) Arduino Nano (Logger): Serial Monitor = SD handshake + “save table” print

File reference: `GroundStation/Ground_Station_NANO/Ground_Station_NANO_Displaying_Serial_Monitor.txt`

### Example (boot/handshake)

```text
--- NANO BOOT ---
SD_CARD: OK
NANO_READY
SD_READY
```

### What you see on boot
The draft shows a handshake like:

- `SD_CARD: OK`
- `NANO_READY`
- `SD_READY`

### What you see when BW16 sends `PKT,...`
For every incoming packet, the Nano prints:

- `GROUND STATION SAVE TELEMETRY TABLE` (a human-readable table)
- then write status, for example:
  - `SD_WRITE_OK` when appended to `cansat.txt`
  - `SD_WRITE_ERR` if append failed

---

## 4) microSD file format (cansat.txt): “Time:” blocks + separator

File reference: `GroundStation/Ground_Station_NANO/Ground_Station_NANO_Save_SD_Card.txt`

### What you see in the file
The draft shows the contents written to `cansat.txt`.

Each entry is a block formatted like:

1. `Time: <millis>`
2. `GROUND STATION SAVE TELEMETRY TABLE` block (same table printed to Serial)
3. a separator line consisting of `---`

Example blocks look like:

```text
Time: 14894

+------------------------------------------------------------------------------+
|                    GROUND STATION SAVE TELEMETRY TABLE                       |
...
---
Time: 17073
...
```

So the SD file becomes a sequence of timestamped blocks for later analysis.

---

## Quick “mental model” of the pipeline

1. **ESP32D** prints a live table and sends `CS1,<...>\n` over LoRa.
2. **BW16** receives `CS1,<...>\n`, parses values, updates LCD, and prints the parsed table.
3. **BW16** forwards parsed data to Nano as `PKT,<...>`.
4. **Nano** prints the save table and appends the same formatted block to `cansat.txt` on microSD.

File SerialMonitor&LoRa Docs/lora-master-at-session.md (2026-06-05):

# LoRa Master AT Session (ESP32D)

This file turns the raw Serial Monitor trace in `CanSat/CanSat_ESP_32D/LoRa_Master.txt` into a readable “session” format.

Source (raw trace):
- `CanSat/CanSat_ESP_32D/LoRa_Master.txt`

---

## 0) AT mode negotiation (as captured)

The trace shows the following sequence (exact spacing depends on terminal settings):

```text
+++           (enter AT)
AT+HELP       (print LoRa Parameter block)
AT+CHANNEL03  (set channel)
+++           (exit AT)
```

---

## 1) Session: defaults + channel + MAC

### Step 1 — inspect parameters
- `+++`
- `AT+HELP`

From the trace’s `LoRa Parameter:` block:
- `MODE:0`
- `LEVEL:0 >> 244.14` (later prints `244.140625bps`)
- `SLEEP:2`
- `Frequency:4372` / `437200000hz`
- `MAC:00,01`
- `Spreading Factor:12`
- `Coding rate:2`
- `CRC:0(false)`
- `Preamble:8`
- `IQ:0(false)`
- `Power:5`

### Step 2 — set channel
- `AT+CHANNEL03`
- response: `+CHANNEL=03` and `OK`

### Step 3 — set MAC (explicit)
- `AT+MAC00,01`
- response: `+MAC=00,01` and `OK`

---

## 2) Session: LEVEL tuning attempt

The trace later shows a tuning attempt:

- `AT+LEVEL` → `+LEVEL=0`
- `AT+LEVEL7` → `OK`

After `AT+LEVEL7`, a subsequent `AT+HELP` output reports:
- `LEVEL:7 >> 13020.833984bps`
- `Spreading Factor:5`
- `Coding rate:2`

> If you change LEVEL on the master, apply the same LEVEL on the slave, otherwise reception may fail.

---

## 3) “Known-good” set for this repo (from the trace)

Use the parameter set matching the `LEVEL:0` / `Spreading Factor:12` part of the log:

- MAC: `00,01`
- Channel: `03`
- Frequency: around `4372 MHz`
- LEVEL: `0`
- Spreading Factor: `12`
- Coding rate: `2`
- CRC: `false`
- Preamble: `8`

For decoded telemetry chain behavior (what the LoRa packet payload looks like), see:
- `README.md`
- `docs/serial-monitor-data-flow.md`

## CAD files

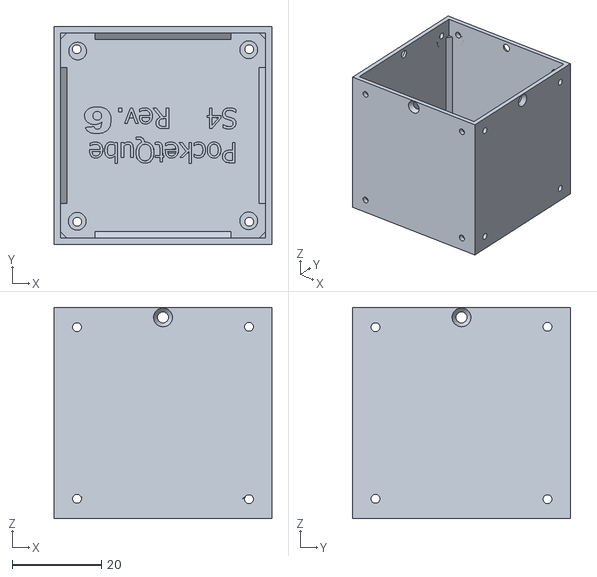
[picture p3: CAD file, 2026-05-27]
CanSat Ground Station chassis design/S4_1p_PocketQube-3.stl
48.8 x 48.8 x 47.3

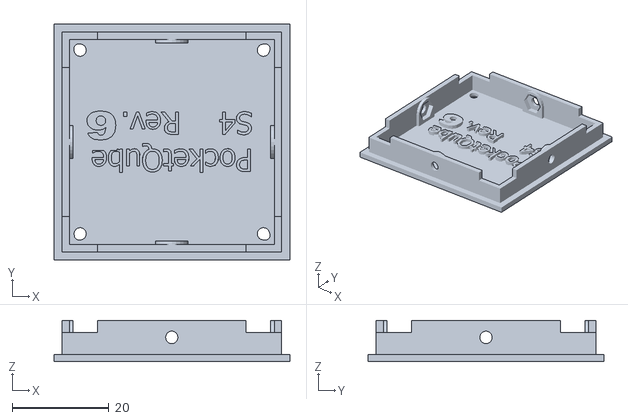
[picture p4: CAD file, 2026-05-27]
CanSat Ground Station chassis design/S4_1p_PocketQube.stl
48.8 x 48.8 x 8.50

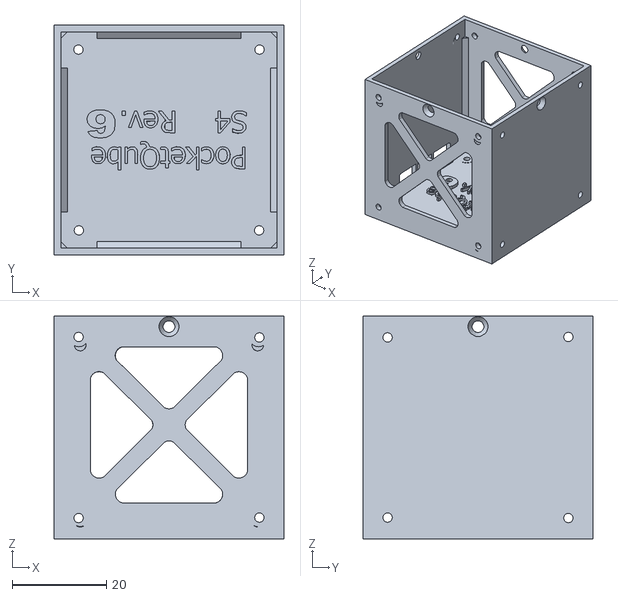
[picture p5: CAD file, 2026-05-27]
CanSat Ground Station chassis design/S4_1p_PocketQube-2.stl
48.8 x 48.8 x 47.3

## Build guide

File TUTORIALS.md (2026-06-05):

# CanSat System Tutorials & Guides

Complete step-by-step guides for setting up, configuring, and troubleshooting your CanSat telemetry system.

---

## 📚 Table of Contents

1. [LoRa Module Configuration](#lora-module-configuration)
2. [Serial Monitor Debugging](#serial-monitor-debugging)
3. [SD Card Data Analysis](#sd-card-data-analysis)
4. [Hardware Assembly & Wiring](#hardware-assembly--wiring)
5. [Firmware Upload Guide](#firmware-upload-guide)

---

## LoRa Module Configuration

Canonical reference (authoritative parameter set):
- `SerialMonitor&LoRa Docs/lora-configuration.md`
- `SerialMonitor&LoRa Docs/lora-master-at-session.md`
- `SerialMonitor&LoRa Docs/lora-slave-at-session.md`

TUTORIALS.md documents the practical workflow + troubleshooting; keep LoRa settings identical on both ends (ESP32D ↔ BW16) using the reference above.

---

### Quick Configuration Checklist

| Parameter | Master (ESP32D) | Slave (BW16) | Notes |
|---|---|---|---|
| MAC Address | `00,01` | `00,01` | **Must match** |
| Channel | `03` | `03` | **Must match** |
| LEVEL | `0` | `0` | **Must match** |
| Frequency | ~4372 MHz | ~4372 MHz | Should result from channel setting |
| Spreading Factor | 12 | 12 | Results from LEVEL=0 |
| Coding Rate | 2 | 2 | Standard LoRa |
| CRC | Disabled (0) | Disabled (0) | false/0 means disabled |
| Preamble | 8 | 8 | Standard length |
| Power | 5 | 5 | Transmit power |

---

### Step-by-Step Master (ESP32D) Configuration

#### Prerequisites

- Arduino IDE with ESP32 board support installed
- USB-to-UART cable connected to ESP32D's serial pins
- LoRa module powered and connected to Serial1 (GPIO 26/27)

#### Configuration Steps

1. **Open Serial Monitor**
   - Arduino IDE → Tools → Serial Monitor
   - Set baud rate to **115200**
   - Set line ending to **"No line ending"** (important!)

2. **Enter AT Mode**
   - Type: `+++` (three plus signs, no spaces or line ending)
   - Press: **Send** button (or Enter after setting "No line ending")
   - Module should respond with a prompt

3. **Check Current Configuration**
   - Type: `AT+HELP`
   - Press: **Send**
   - Module prints all current LoRa parameters

4. **Configure MAC Address**
   - Type: `AT+MAC00,01`
   - Press: **Send**
   - Expected response: `+MAC=00,01` then `OK`

5. **Configure Channel**
   - Type: `AT+CHANNEL03`
   - Press: **Send**
   - Expected response: `+CHANNEL=03` then `OK`

6. **Configure Spreading Factor (LEVEL)**
   - For longer range (slower data): `AT+LEVEL0`
   - For shorter range (faster data): `AT+LEVEL7`
   - Type: `AT+LEVEL0`
   - Press: **Send**
   - Expected response: `OK`

7. **Verify Configuration**
   - Type: `AT+HELP` again
   - Verify MAC, CHANNEL, Frequency, and Spreading Factor

8. **Exit AT Mode**
   - Type: `+++`
   - Press: **Send**
   - Module exits AT mode and resumes normal operation

#### Example Master Configuration Session

```
>>> +++
(AT mode prompt)

>>> AT+HELP
LoRa Parameter:
MODE:0
LEVEL:0 >> 244.140625bps
SLEEP:2
Frequency:4372
MAC:00,01
Spreading Factor:12
Coding rate:2
CRC:0(false)
Preamble:8
IQ:0(false)
Power:5

>>> AT+MAC00,01
+MAC=00,01
OK

>>> AT+CHANNEL03
+CHANNEL=03
OK

>>> AT+LEVEL0
OK

>>> AT+HELP
LoRa Parameter:
MODE:0
LEVEL:0 >> 244.140625bps
SLEEP:2
Frequency:4372
MAC:00,01
Spreading Factor:12
Coding rate:2
CRC:0(false)
Preamble:8
IQ:0(false)
Power:5

>>> +++
(exits AT mode)
```

---

### Step-by-Step Slave (BW16) Configuration

**Repeat the exact same steps as the Master, ensuring:**

1. **MAC, CHANNEL, and LEVEL match the Master exactly**
2. Serial Monitor is set to 115200 baud
3. LoRa module is connected to Serial1 (PB1/PB2 on BW16)

After configuration, both modules should show identical MAC, CHANNEL, LEVEL, and FREQUENCY values in `AT+HELP` output.

---

### LEVEL Settings & Data Rates

The LEVEL parameter controls the spreading factor and thus the range/speed trade-off:

| LEVEL | Spreading Factor | Bitrate | Range | Use Case |
|---|---|---|---|---|
| **0** | 12 | 244 bps | ~12 km | **Default (longest range)** |
| 1 | 11 | 434 bps | ~10 km | Medium range |
| 2 | 10 | 781 bps | ~8 km | Faster data |
| 3 | 9 | 1465 bps | ~6 km | Even faster |
| 4 | 8 | 2734 bps | ~4 km | High speed |
| 5 | 7 | 5468 bps | ~2 km | Very high speed |
| 6 | 6 | 10937 bps | ~1 km | Near-field only |
| **7** | 5 | 13020 bps | ~500 m | **Fastest (short range)** |

**Recommendation:** Use **LEVEL 0** for maximum range and reliability with stationary ground station. Use **LEVEL 7** if range is <500m and you need faster sensor readings.

---

### Troubleshooting LoRa Configuration

| Issue | Cause | Solution |
|---|---|---|
| **Module won't enter AT mode** | Baud rate wrong or connection loose | Verify 115200 baud, check UART connections |
| **`AT+HELP` shows different MAC/CHANNEL** | Module not configured | Run configuration steps again |
| **No packets received after config** | LEVEL/MAC/CHANNEL mismatch between master/slave | Verify both modules have identical values via `AT+HELP` |
| **Packets received but corrupted** | Spreading factor or frequency mismatch | Ensure SF and frequency match on both modules |
| **Very short range** | Power setting too low | Increase with `AT+POWER7` (max) |
| **CRC errors in logs** | CRC enabled when it shouldn't be | Ensure `AT+HELP` shows `CRC:0(false)` |

---

## Serial Monitor Debugging

### Output Overview by Board

Each board prints different information to Serial Monitor at different baud rates:

| Board | Baud Rate | Output | Frequency |
|---|---|---|---|
| **ESP32D** | 115200 | Sensor readings + LoRa TX status | Every 2 seconds |
| **BW16** | 115200 | Parsed telemetry + forwarding info | On packet RX |
| **Nano** | 9600 | SD write status + saved data | On packet RX |

---

### ESP32D Transmitter Output

**What you should see:**

```
--- CANSAT MISSION READY ---
Waiting for sensors to stabilize...

+------------------------------------------------------------------------------+
|                        CANSAT LIVE TELEMETRY TABLE                           |
+----------------------+---------------------------+---------------------------+
| DHT22                | Humidity                  | 37.80 %                   |
| DHT22                | Temperature               | 25.70 C                   |
+----------------------+---------------------------+---------------------------+
| BMP180               | Pressure                  | 93099 Pa                  |
| BMP180               | Altitude (Est)            | 707.93 m                  |
| BMP180               | Temperature (Internal)    | 28.20 C                   |
+----------------------+---------------------------+---------------------------+
| MPU6050              | Accel X / Y / Z           | -0.5, -0.4, 11.0          |
| MPU6050              | Gyro X / Y / Z            | -0.1, 0.0, -0.0           |
| MPU6050              | Temperature (Die)         | 26.13 C                   |
+----------------------+---------------------------+---------------------------+
| NEO-6M GPS           | Fix Status                | NO FIX / SEARCHING        |
+----------------------+---------------------------+---------------------------+
| DX-LR03-LoRa         | Radio Status              | ONLINE (TX OK)            |
| DX-LR03-LoRa         | Last Packet Size          | 62 Bytes                  |
| DX-LR03-LoRa         | Frequency Band            | 433 MHz                   |
+----------------------+---------------------------+---------------------------+

[STATUS] CanSat transmitter is operational
```

**What each line means:**

- **DHT22 rows:** Current humidity and temperature from the DHT22 sensor
- **BMP180 rows:** Atmospheric pressure, altitude estimate, and internal sensor temperature
- **MPU6050 rows:** Acceleration vector (X, Y, Z) and rotation rates (gyroscope)
- **NEO-6M GPS row:** GPS fix status (`NO FIX` = still searching for satellites)
- **DX-LR03 rows:** LoRa radio status and last transmitted packet size
- **[STATUS] line:** Heartbeat message (appears every 10 seconds)

---

### BW16 Ground Station Receiver Output

**Boot sequence (what you should see on startup):**

```
--- GROUND STATION BOOTING (BW16) ---
[OK] LoRa UART (Serial1) Initialized.
BW16_HELLO
SD_STATUS
[STATION ALIVE] Total Packets: 0
SD_STATUS
[SD] Status changed: READY
```

**Meaning:**
- `[OK] LoRa UART...` → LoRa module is responding
- `BW16_HELLO` → BW16 sends greeting to Nano
- `SD_STATUS` → BW16 polls Nano for SD card status
- `[SD] Status changed: READY` → Nano reports SD card is available

**Live packet reception (repeats for each LoRa packet):**

```
+------------------------------------------------------------------------------+
|                    GROUND STATION LIVE TELEMETRY TABLE                       |
+----------------------+---------------------------+---------------------------+
| DHT22                | Temperature               | 23.00 C                   |
| DHT22                | Humidity                  | 40.60 %                   |
...
| Nano SD Logger       | Card Status               | VIA NANO                  |
+----------------------+---------------------------+---------------------------+

PKT,60,0,23.00,40.60,93366.00,684.70,0.000000,0.000000,-0.60,-0.50,11.00,4.06
[STATION ALIVE] Total Packets: 1
```

**Meaning:**
- Telemetry table: Parsed sensor values from the received LoRa packet
- `PKT,60,0,...`: Raw forwarding command to Nano (packet size, packet number, sensor data)
- `[STATION ALIVE]`: Heartbeat message with total packet count

---

### Arduino Nano Logger Output

**Boot sequence (9600 baud):**

```
--- NANO BOOT ---
SD_CARD: OK
NANO_READY
SD_READY
```

**Meaning:**
- `SD_CARD: OK` → SD card detected and initialized
- `NANO_READY` → Nano firmware is running
- `SD_READY` → SD card is ready for writes

**Packet reception (repeats for each PKT command from BW16):**

```
+------------------------------------------------------------------------------+
|                    GROUND STATION SAVE TELEMETRY TABLE                       |
+----------------------+---------------------------+---------------------------+
| DHT22                | Temperature               | 23.00C                    |
| DHT22                | Humidity                  | 40.60%                    |
...
+----------------------+---------------------------+---------------------------+

SD_WRITE_OK
SD_READY
```

**Meaning:**
- Telemetry table: Same data received from BW16
- `SD_WRITE_OK` → Data successfully appended to `cansat.txt`
- `SD_READY` → SD card still available

---

### Debug Checklist

✅ **All three Serial Monitors showing data?**
  1. ESP32D prints telemetry table every 2 seconds
  2. BW16 prints received packets
  3. Nano prints saved packets and `SD_WRITE_OK`
  
✅ **BW16 not receiving from ESP32D?**
  1. Verify LoRa module MAC/CHANNEL/LEVEL match
  2. Check UART connections (GPIO 26/27 on ESP32D → Serial1)
  3. Look for LoRa errors in BW16 Serial Monitor
  
✅ **Nano not receiving from BW16?**
  1. Verify BW16 can reach Nano (check BW16 Serial Monitor for `PKT,` lines)
  2. Check UART connections (PA7/PA8 on BW16 → D0/D1 on Nano)
  3. Verify baud rate is 9600 on Nano (not 115200)

---

## SD Card Data Analysis

### Reading the Data

#### On the Nano's microSD card:

The file `cansat.txt` contains timestamped blocks of telemetry data:

```
Time: 14894

+──────────────────────────────────────────────────
| GROUND STATION SAVE TELEMETRY TABLE              |
+──────────────────────────────────────────────────
| DHT22     | Temperature   | 23.00C              |
| DHT22     | Humidity      | 40.60%              |
| BMP180    | Pressure      | 93366Pa             |
| BMP180    | Altitude      | 684.70m             |
| MPU6050   | Accel X/Y/Z   | -0.6, -0.5, 11.0   |
| NEO-6M    | Fix Status    | NO FIX / SEARCHING  |
| LoRa      | Packet Size   | 60Bytes             |
| LoRa      | Packet Number | 0                   |
+──────────────────────────────────────────────────

---
Time: 17073

...
```

#### To recover the data:

1. **Remove microSD card from Nano**
2. **Insert into PC's SD card reader**
3. **Copy `cansat.txt` to computer**
4. **Open in any text editor** (Notepad, VS Code, etc.)

---

### Parsing Data Programmatically

#### Python Script Example

```python
import re

def parse_cansat_log(filename):
    """Parse cansat.txt and extract telemetry records."""
    
    with open(filename, 'r') as f:
        content = f.read()
    
    # Split by separator
    blocks = content.split('---')
    records = []
    
    for block in blocks:
        if not block.strip():
            continue
        
        record = {}
        
        # Extract timestamp
        time_match = re.search(r'Time:\s*(\d+)', block)
        if time_match:
            record['time_ms'] = int(time_match.group(1))
        
        # Extract temperature
        temp_match = re.search(r'Temperature\s*\|\s*([\d.]+)', block)
        if temp_match:
            record['temp_c'] = float(temp_match.group(1))
        
        # Extract humidity
        hum_match = re.search(r'Humidity\s*\|\s*([\d.]+)', block)
        if hum_match:
            record['humidity_%'] = float(hum_match.group(1))
        
        # Extract pressure
        press_match = re.search(r'Pressure\s*\|\s*([\d.]+)', block)
        if press_match:
            record['pressure_pa'] = float(press_match.group(1))
        
        # Extract altitude
        alt_match = re.search(r'Altitude\s*\|\s*([\d.]+)', block)
        if alt_match:
            record['altitude_m'] = float(alt_match.group(1))
        
        # Extract accel
        accel_match = re.search(r'Accel\s*\|\s*([\d\-., ]+)', block)
        if accel_match:
            accel_str = accel_match.group(1)
            accel_vals = [float(x.strip()) for x in accel_str.split(',')]
            record['accel_x'], record['accel_y'], record['accel_z'] = accel_vals
        
        if record:
            records.append(record)
    
    return records

# Usage
if __name__ == "__main__":
    records = parse_cansat_log('cansat.txt')
    
    for i, rec in enumerate(records):
        print(f"Record {i}: Time={rec.get('time_ms')}ms, "
              f"Temp={rec.get('temp_c')}°C, "
              f"Humidity={rec.get('humidity_%')}%, "
              f"Pressure={rec.get('pressure_pa')}Pa")
```

---

### Creating a Spreadsheet

1. **Copy data from `cansat.txt`** into a text file
2. **Open Excel or LibreOffice Calc**
3. **Data → Text to Columns** (if needed)
4. **Create columns:** Time, Temperature, Humidity, Pressure, Altitude, Accel_X, Accel_Y, Accel_Z
5. **Plot charts** using the time-series data

---

## Hardware Assembly & Wiring

### Transmitter (ESP32D) Assembly

#### Step 1: Identify Components

- ESP32 development board
- DHT22 sensor
- BMP180 barometric sensor
- MPU6050 accelerometer/gyroscope
- NEO-6M GPS module
- DX-LR03 LoRa module (433 MHz)
- Breadboard and jumper wires
- 10kΩ resistor for DHT22 pull-up

#### Step 2: Connect DHT22 (Temperature/Humidity)

| DHT22 Pin | ESP32 Pin |
|---|---|
| VCC | 3.3V |
| GND | GND |
| DATA | GPIO 4 (with 10kΩ pull-up to 3.3V) |

**Pull-up resistor:** Connect 10kΩ resistor between DHT22 DATA pin and 3.3V rail.

#### Step 3: Connect BMP180 & MPU6050 (I2C Bus)

Both sensors share the I2C bus (GPIO 21/22):

| Sensor | Pin | ESP32 Pin |
|---|-----|---|
| BMP180 / MPU6050 | VCC | 3.3V |
| BMP180 / MPU6050 | GND | GND |
| BMP180 / MPU6050 | SDA | GPIO 21 |
| BMP180 / MPU6050 | SCL | GPIO 22 |

#### Step 4: Connect NEO-6M GPS (Serial2)

| GPS Pin | ESP32 Pin |
|---|---|
| VCC | 3.3V |
| GND | GND |
| TX | GPIO 16 (RX2) |
| RX | GPIO 17 (TX2) |

#### Step 5: Connect DX-LR03 LoRa (Serial1)

| LoRa Pin | ESP32 Pin |
|---|---|
| VCC | 3.3V |
| GND | GND |
| TX | GPIO 26 (RX1) |
| RX | GPIO 27 (TX1) |

---

### Ground Station (BW16) Assembly

#### Step 1: Connect LoRa Module (Serial1)

| LoRa Pin | BW16 Pin |
|---|---|
| VCC | 3.3V or 5V |
| GND | GND |
| TX | PB2 (RX1) |
| RX | PB1 (TX1) |

#### Step 2: Connect ST7920 LCD (SPI)

| LCD Pin | Pin Name | BW16 Pin |
|---|---|---|
| E (Clock) | SCLK | PA25 |
| RW (Data) | SID | PA27 |
| RS (Select) | CS | PA26 |
| PSB | - | GND **[CRITICAL]** |
| VCC | - | 5V |
| GND | - | GND |

**Critical:** PSB must be connected to GND to select **serial mode**. This determines how the LCD communicates with the BW16.

#### Step 3: Connect Status LEDs

| LED Color | Anode Pin | Cathode |
|---|---|---|
| Green (LoRa) | PA30 | GND (via 220Ω resistor) |
| Blue (SD) | PA7 | GND (via 220Ω resistor) |
| Red (Monitor) | PA12 | GND (via 220Ω resistor) |

#### Step 4: Connect Arduino Nano (UART Bridge)

| Signal | BW16 Pin | Nano Pin |
|---|---|---|
| TX | PA7 | D0 (RX) |
| RX | PA8 | D1 (TX) |
| GND | GND | GND |

**⚠️ Voltage Warning:** Use a **logic level shifter** or **voltage divider** on Nano TX (D1) → BW16 RX (PA8) because Nano is 5V and BW16 is 3.3V.

---

### Data Logger (Arduino Nano) Assembly

#### Step 1: Connect SD Card Adapter (SPI)

| Adapter Pin | Nano Pin |
|---|---|
| VCC | 5V |
| GND | GND |
| CS | D10 |
| MOSI | D11 |
| MISO | D12 |
| SCK | D13 |

#### Step 2: Connect Status LED

| LED | Anode Pin | Cathode |
|-----|---|---|
| Blue (SD Write) | D9 | GND (via 220Ω resistor) |

#### Step 3: Connect UART from BW16

| Signal | Nano Pin | From BW16 Pin |
|---|---|---|
| RX | D0 | PA7 (with level shifter/divider) |
| TX | D1 | PA8 (with level shifter/divider) |
| GND | GND | GND |

---

### Power Distribution

For a lab setup with USB power:

1. **ESP32D:** Powered via USB (3.3V regulator on board)
2. **BW16:** Powered via USB-C (provides 5V)
3. **Arduino Nano:** Powered from BW16's 5V rail (or separate USB)
4. **LCD:** 5V from BW16
5. **LoRa modules:** 3.3V regulated (check module variant)
6. **SD card adapter:** 5V input (on-board regulator converts to 3.3V)

For a field setup with LiPo battery (on ESP32D):

1. **ESP32D:** Powered via LiPo battery (3.7–4.2V) with on-board regulator to 3.3V
2. **BW16:** Powered via USB-C power bank or line power (5V)
3. **Nano:** Powered from BW16's 5V or separate power bank

---

## Firmware Upload Guide

### Prerequisites

- Arduino IDE (v1.8.13 or later)
- USB-to-UART cables (CH340G or FT232RL based)
- Board definitions installed (ESP32, BW16, Arduino Nano)
- Required libraries installed (see README)

---

### Option 1: Upload to ESP32D (Transmitter)

1. **Connect USB cable to ESP32D**
   - ESP32D has a built-in USB-C or micro-USB port

2. **Open Arduino IDE**
   - File → Open → `CanSat/CanSat_ESP_32D/CanSat_ESP_32D.ino`

3. **Select Board & Port**
   - Tools → Board → ESP32 → **ESP32 Dev Module**
   - Tools → Port → `/dev/ttyUSB0` (or your port)
   - Tools → Upload Speed → **921600**

4. **Upload**
   - Click **Upload** button
   - Wait for `Uploading...` to complete

5. **Verify**
   - Open Serial Monitor (115200 baud)
   - You should see: `CANSAT MISSION READY - TRANSMITTER`

---

### Option 2: Upload to BW16 (Receiver)

1. **Connect USB cable to BW16**
   - BW16 may require a USB-to-UART adapter

2. **Open Arduino IDE**
   - File → Open → `GroundStation/Ground_Station_BW16/Ground_Station_BW16.ino`

3. **Select Board & Port**
   - Tools → Board → **BW16** (or Arduino Leonardo as fallback)
   - Tools → Port → `/dev/ttyUSB1` (or your port)
   - Tools → Upload Speed → **115200**

4. **Upload**
   - Click **Upload** button

5. **Verify**
   - Open Serial Monitor (115200 baud)
   - You should see: `--- GROUND STATION BOOTING (BW16) ---`

---

### Option 3: Upload to Arduino Nano (Logger)

1. **Connect USB cable to Nano**
   - Nano has a micro-USB port

2. **Open Arduino IDE**
   - File → Open → `GroundStation/Ground_Station_NANO/Ground_Station_NANO.ino`

3. **Select Board & Port**
   - Tools → Board → **Arduino Nano**
   - Tools → Processor → **ATmega328P**
   - Tools → Port → `/dev/ttyUSB2` (or your port)
   - Tools → Upload Speed → **115200**

4. **Upload**
   - Click **Upload** button

5. **Verify**
   - Open Serial Monitor (9600 baud)
   - You should see: `--- NANO BOOT ---`

---

### Troubleshooting Upload Issues

| Issue | Solution |
|---|---|
| **COM port not detected** | Install driver (CH340G/FT232RL), restart IDE |
| **Board not detected** | Ensure board definition installed (Tools → Boards Manager) |
| **Upload timeout** | Lower baud rate, check USB cable, try different port |
| **Compilation error** | Verify all required libraries installed |
| **Sketch too large** | Remove debug serial output, optimize code |

---

**Next Steps:**
- [Configure LoRa modules](#lora-module-configuration) (AT commands)
- [Check Serial Monitor output](#serial-monitor-debugging) (data validation)
- [Analyze SD card data](#sd-card-data-analysis) (data retrieval)

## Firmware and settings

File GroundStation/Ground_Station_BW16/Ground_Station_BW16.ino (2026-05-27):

// ============================================================
// CANSAT GROUND STATION – BW16 (RTL8720DN)
// LED LOGIC:
// - Red LED: ON continuous, blinks on every LCD update (non‑blocking)
// - Green LED: ON continuous, blinks on every LoRa packet received (non‑blocking)
// - Blue LED: SD card status (ON = ready, OFF = fail)
// ============================================================

#include <Arduino.h>
#include <SPI.h>
#include <U8g2lib.h>
#include <SoftwareSerial.h>

// ---- LED logic levels ----
#define LED_ON  HIGH
#define LED_OFF LOW

// ---- Pin definitions ----
#define LED_LORA_GREEN PA30   // Green LED (LoRa activity)
#define LED_SD_BLUE    PA7    // Blue LED (SD status)
#define LED_MON_RED    PA12   // Red LED (LCD monitor activity)

// Internal RGB (used as same functions)
#define RGB_RED        PA13
#define RGB_GREEN      PA14
#define RGB_BLUE       PB3

// LCD SPI
#define LCD_E          PA25
#define LCD_SID        PA27
#define LCD_CS         PA26

SoftwareSerial nanoSerial(PA8, PA7);  // RX=PA8, TX=PA7 to Arduino Nano
U8G2_ST7920_128X64_F_SW_SPI u8g2(U8G2_R0, LCD_E, LCD_SID, LCD_CS, U8X8_PIN_NONE);

// Telemetry variables
float t_dht=0, hum=0, press=0, alt=0, lat=0, lng=0, ax=0, ay=0, az=0, tilt=0;
int pktNum=0, lastPktSize=0;      
unsigned long packetCount=0, lastHeartbeat=0, lastStatusRequest=0, lastPktSentTime=0;
bool nanoConnected = false, firstPacketReceived = false, waitingForAck = false;

// Debounce for LCD updates and status
unsigned long lastStatusChange = 0;
bool lastProcessedState = false;
unsigned long lastLcdUpdate = 0;

// Non‑blocking LED blink timers
unsigned long lastRedBlink = 0;
bool redBlinkActive = false;
unsigned long lastGreenBlink = 0;
bool greenBlinkActive = false;

// ------------------------------------------------------------------
// Non‑blocking LED control helpers
// ------------------------------------------------------------------
void setLcdLed(int state) {
    digitalWrite(LED_MON_RED, state);
    digitalWrite(RGB_RED, state);
}

void setLoRaLed(int state) {
    digitalWrite(LED_LORA_GREEN, state);
    digitalWrite(RGB_GREEN, state);
}

void setSdLed(int state) {
    digitalWrite(LED_SD_BLUE, state);
    digitalWrite(RGB_BLUE, state);
}

// Red blink: turns LED off for 30ms, then back on (non‑blocking)
void blinkRedAsync() {
    if (redBlinkActive) return;       // already blinking
    redBlinkActive = true;
    lastRedBlink = millis();
    setLcdLed(LED_OFF);
}

// Green blink: turns LED off for 30ms, then back on (non‑blocking)
void blinkGreenAsync() {
    if (greenBlinkActive) return;
    greenBlinkActive = true;
    lastGreenBlink = millis();
    setLoRaLed(LED_OFF);
}

void updateBlinkTimers() {
    unsigned long now = millis();
    if (redBlinkActive && (now - lastRedBlink >= 30)) {
        setLcdLed(LED_ON);
        redBlinkActive = false;
    }
    if (greenBlinkActive && (now - lastGreenBlink >= 30)) {
        setLoRaLed(LED_ON);
        greenBlinkActive = false;
    }
}

// ------------------------------------------------------------------
void requestSDStatus() {
    nanoSerial.println("SD_STATUS");
    lastStatusRequest = millis();
}

void sendPKTtoNano() {
    if (!nanoConnected) return;
    // Format: packetSize, packetNum, t, hum, press, alt, lat, lng, ax, ay, az, tilt
    nanoSerial.print("PKT,");
    nanoSerial.print(lastPktSize); nanoSerial.print(",");
    nanoSerial.print(pktNum); nanoSerial.print(",");
    nanoSerial.print(t_dht, 2); nanoSerial.print(",");
    nanoSerial.print(hum, 2); nanoSerial.print(",");
    nanoSerial.print(press, 2); nanoSerial.print(",");
    nanoSerial.print(alt, 2); nanoSerial.print(",");
    nanoSerial.print(lat, 6); nanoSerial.print(",");
    nanoSerial.print(lng, 6); nanoSerial.print(",");
    nanoSerial.print(ax, 2); nanoSerial.print(",");
    nanoSerial.print(ay, 2); nanoSerial.print(",");
    nanoSerial.print(az, 2); nanoSerial.print(",");
    nanoSerial.println(tilt, 2);
    waitingForAck = true;
    lastPktSentTime = millis();
}

// ------------------------------------------------------------------
void setup() {
    pinMode(LED_LORA_GREEN, OUTPUT);
    pinMode(LED_SD_BLUE, OUTPUT);
    pinMode(LED_MON_RED, OUTPUT);
    pinMode(RGB_RED, OUTPUT);
    pinMode(RGB_GREEN, OUTPUT);
    pinMode(RGB_BLUE, OUTPUT);

    // Start with all LEDs off
    setLcdLed(LED_OFF);
    setLoRaLed(LED_OFF);
    setSdLed(LED_OFF);

    Serial.begin(115200);
    nanoSerial.begin(9600);
    delay(2000);

    Serial.println("--- GROUND STATION BOOTING (BW16) ---");

    // Initialise LCD
    u8g2.begin();
    setLcdLed(LED_ON);      // Red LED ON (LCD active)
    u8g2.clearBuffer();
    u8g2.setFont(u8g2_font_6x10_tf);
    u8g2.drawStr(20, 35, "INIT SYSTEM...");
    u8g2.sendBuffer();
    blinkRedAsync();        // Non‑blocking blink after first draw

    // Initialise LoRa UART (Serial1)
    Serial1.begin(9600);
    Serial.println("[OK] LoRa UART (Serial1) Initialized.");
    setLoRaLed(LED_ON);     // Green LED ON (LoRa module ready)

    // Handshake with Arduino Nano
    nanoSerial.println("BW16_HELLO");
    delay(500);
    unsigned long startTime = millis();
    while (millis() - startTime < 2000) {
        if (nanoSerial.available()) {
            String response = nanoSerial.readStringUntil('\n');
            response.trim();
            if (response == "NANO_READY") {
                requestSDStatus();
                delay(100);
                if (nanoSerial.available()) {
                    String sdResp = nanoSerial.readStringUntil('\n');
                    sdResp.trim();
                    if (sdResp == "SD_READY") {
                        nanoConnected = true;
                        setSdLed(LED_ON);
                    } else {
                        nanoConnected = false;
                        setSdLed(LED_OFF);
                    }
                }
                break;
            }
        }
    }
    if (!nanoConnected) setSdLed(LED_OFF);
    displayWaitingScreen();
}

// ------------------------------------------------------------------
void displayWaitingScreen() {
    u8g2.clearBuffer();
    u8g2.setFont(u8g2_font_6x10_tf);
    u8g2.drawStr(15, 12, "GROUND STATION");
    u8g2.drawHLine(0, 15, 128);
    u8g2.drawStr(0, 35, "SD Card: ");
    u8g2.drawStr(65, 35, nanoConnected ? "VIA NANO" : "OFFLINE");
    u8g2.drawStr(0, 50, "Waiting for LoRa...");
    u8g2.sendBuffer();
    blinkRedAsync();
}

// ------------------------------------------------------------------
bool parseTelemetry(String data) {
    if (!data.startsWith("CS1,")) return false;
    lastPktSize = data.length();   // store for forwarding to Nano
    String payload = data.substring(4);
    int fieldIndex = 0, startPos = 0, commaPos = payload.indexOf(',');
    // Fields: t_dht, hum, press, alt, lat, lng, ax, ay, az, pktNum
    while (fieldIndex <= 10) {
        String field = (commaPos == -1) ? payload.substring(startPos) : payload.substring(startPos, commaPos);
        field.trim();
        switch (fieldIndex) {
            case 0: t_dht = field.toFloat(); break;
            case 1: hum   = field.toFloat(); break;
            case 2: press = field.toFloat(); break;
            case 3: alt   = field.toFloat(); break;
            case 4: lat   = field.toFloat(); break;
            case 5: lng   = field.toFloat(); break;
            case 6: ax    = field.toFloat(); break;
            case 7: ay    = field.toFloat(); break;
            case 8: az    = field.toFloat(); break;
            case 9: pktNum = field.toInt();  break;
        }
        if (commaPos == -1) break;
        startPos = commaPos + 1;
        commaPos = payload.indexOf(',', startPos);
        fieldIndex++;
    }

    float magnitude = sqrt(ax*ax + ay*ay + az*az);
    if (magnitude > 0.1) tilt = acos(az / magnitude) * 180.0 / PI;
    return true;
}

// ------------------------------------------------------------------
void updateLCD() {
    u8g2.clearBuffer();
    u8g2.setFont(u8g2_font_5x7_tf);

    u8g2.drawStr(0, 7, "CANSAT LIVE DASHBOARD");
    u8g2.drawHLine(0, 9, 128);
    u8g2.setCursor(0, 18); u8g2.print("Pkt:"); u8g2.print(pktNum);
    u8g2.setCursor(0, 27); u8g2.print("Tmp:"); u8g2.print(t_dht, 1); u8g2.print("C");
    u8g2.setCursor(0, 36); u8g2.print("Hum:"); u8g2.print(hum, 0); u8g2.print("%");
    u8g2.setCursor(0, 45); u8g2.print("Prs:"); u8g2.print(press/100, 0); u8g2.print("hPa");
    u8g2.setCursor(64, 18); u8g2.print("Alt:"); u8g2.print(alt, 1); u8g2.print("m");
    u8g2.setCursor(64, 27); u8g2.print("Tlt:"); u8g2.print(tilt, 1); u8g2.print("deg");
    u8g2.setCursor(64, 36); u8g2.print("AccZ:"); u8g2.print(az, 1);
    u8g2.setCursor(64, 45); u8g2.print("SD :"); u8g2.print(nanoConnected ? "OK" : "ERR");
    u8g2.setCursor(0, 54); u8g2.print("A(X,Y): "); u8g2.print(ax, 1); u8g2.print(","); u8g2.print(ay, 1);
    u8g2.drawHLine(0, 56, 128);
    u8g2.setCursor(0, 63);
    if(lat != 0) {
        u8g2.print("GPS:"); u8g2.print(lat, 4); u8g2.print(","); u8g2.print(lng, 4);
    } else {
        u8g2.print("GPS: SEARCHING...");
    }
    u8g2.sendBuffer();
    blinkRedAsync();
}

// ------------------------------------------------------------------
void printTelemetryTable() {
    Serial.println("\n+------------------------------------------------------------------------------+");
    Serial.println("|                    GROUND STATION LIVE TELEMETRY TABLE                       |");
    Serial.println("+----------------------+---------------------------+---------------------------+");
    Serial.println("| SENSOR               | PARAMETER                 | VALUE                     |");
    Serial.println("+----------------------+---------------------------+---------------------------+");
    Serial.print("| DHT22                | Temperature               | "); Serial.print(t_dht); Serial.println(" C                   |");
    Serial.print("| DHT22                | Humidity                  | "); Serial.print(hum); Serial.println(" %                   |");
    Serial.println("+----------------------+---------------------------+---------------------------+");
    Serial.print("| BMP180               | Pressure                  | "); Serial.print(press, 0); Serial.println(" Pa                  |");
    Serial.print("| BMP180               | Altitude (Est)            | "); Serial.print(alt); Serial.println(" m                  |");
    Serial.println("+----------------------+---------------------------+---------------------------+");
    Serial.print("| MPU6050              | Accel X / Y / Z           | ");
    Serial.print(ax, 1); Serial.print(", "); Serial.print(ay, 1); Serial.print(", "); Serial.print(az, 1); Serial.println("          |");
    Serial.println("+----------------------+---------------------------+---------------------------+");
    if (lat != 0) {
        Serial.print("| NEO-6M GPS           | Latitude                  | "); Serial.println(lat, 6);
        Serial.print("| NEO-6M GPS           | Longitude                 | "); Serial.println(lng, 6);
    } else {
        Serial.println("| NEO-6M GPS           | Fix Status                | NO FIX / SEARCHING        |");
    }
    Serial.println("+----------------------+---------------------------+---------------------------+");
    Serial.println("| CONNECTION INFO      | PARAMETER                 | VALUE                     |");
    Serial.println("+----------------------+---------------------------+---------------------------+");
    Serial.print("| DX-LR03-LoRa         | Last Packet Size          | "); Serial.print(lastPktSize); Serial.println(" Bytes                  |");
    Serial.print("| DX-LR03-LoRa         | Packet Number             | "); Serial.print(pktNum); Serial.println("                         |");
    Serial.println("+----------------------+---------------------------+---------------------------+");
    Serial.print("| Nano SD Logger       | Card Status               | "); Serial.print(nanoConnected ? "VIA NANO" : "OFFLINE"); Serial.println("                  |");
    Serial.println("+----------------------+---------------------------+---------------------------+");
}

// ------------------------------------------------------------------
void loop() {
    updateBlinkTimers();   // handle non‑blocking LED blinks

    // 1. Process LoRa packets
    if (Serial1.available()) {
        String received = Serial1.readStringUntil('\n');
        received.trim();
        if (received.length() > 0 && parseTelemetry(received)) {
            packetCount++;
            blinkGreenAsync();   // non‑blocking green blink

            if (!firstPacketReceived) {
                firstPacketReceived = true;
                updateLCD();
                lastLcdUpdate = millis();
            } else {
                // Throttle LCD updates to max 10 fps (100ms)
                if (millis() - lastLcdUpdate >= 100) {
                    updateLCD();
                    lastLcdUpdate = millis();
                }
            }
            printTelemetryTable();
            sendPKTtoNano();
        }
    }

    // 2. Process incoming messages from Nano (SD status updates)
    if (nanoSerial.available()) {
        String nanoMsg = nanoSerial.readStringUntil('\n');
        nanoMsg.trim();
        bool newState = nanoConnected;

        if (nanoMsg == "SD_WRITE_OK") {
            newState = true;
            waitingForAck = false;
        }
        else if (nanoMsg == "SD_WRITE_ERR") {
            newState = false;
            waitingForAck = false;
        }
        else if (nanoMsg == "SD_READY") {
            newState = true;
        }
        else if (nanoMsg == "SD_FAIL") {
            newState = false;
        }

        // Update only if state actually changed, debounce rapid toggles
        if (newState != lastProcessedState && (millis() - lastStatusChange > 500)) {
            lastProcessedState = newState;
            lastStatusChange = millis();
            nanoConnected = newState;
            setSdLed(newState ? LED_ON : LED_OFF);

            if (firstPacketReceived) updateLCD();
            else displayWaitingScreen();

            Serial.print("[SD] Status changed: ");
            Serial.println(newState ? "READY" : "FAIL");
        }
    }

    // 3. Timeout for missing ack
    if (waitingForAck && (millis() - lastPktSentTime > 300)) {
        waitingForAck = false;
        requestSDStatus();
    }

    // 4. Poll SD status every 5 seconds (reduced from 2s)
    if (millis() - lastStatusRequest > 5000) {
        requestSDStatus();
    }

    // 5. Redraw waiting screen periodically if no packet yet (every 2s)
    if (!firstPacketReceived && (millis() % 2000 < 50)) {
        displayWaitingScreen();
    }

    // 6. Health heartbeat (every 5 seconds)
    if (millis() - lastHeartbeat >= 5000) {
        lastHeartbeat = millis();
        Serial.print("[STATION ALIVE] Total Packets: "); Serial.println(packetCount);
        if (!nanoConnected && (millis() % 30000 < 1000)) {
            nanoSerial.println("PING");
            delay(50);
            if (nanoSerial.available()) {
                String resp = nanoSerial.readStringUntil('\n');
                if (resp == "PONG") requestSDStatus();
            }
        }
    }
}

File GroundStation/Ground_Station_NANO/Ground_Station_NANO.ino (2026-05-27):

#include <SPI.h>
#include <SD.h>

#define SD_CS            10      
#define LED_BLUE         9       
#define CHECK_INTERVAL   5000    // Reduced polling frequency (was 2000)

char dataFile[] = "cansat.txt";

bool sdReady = false;
unsigned long lastCheck = 0;
bool lastReportedState = false;

// Debounce counters
byte failCounter = 0;
byte successCounter = 0;

// Skip checks during write (prevent interference)
volatile bool isWriting = false;

void setup() {
    pinMode(LED_BLUE, OUTPUT);
    digitalWrite(LED_BLUE, LOW); 
    Serial.begin(9600);
    
    Serial.println(F("--- NANO BOOT ---"));
    if (SD.begin(SD_CS)) {
        sdReady = true;
        lastReportedState = true;
        digitalWrite(LED_BLUE, HIGH);
        Serial.println(F("SD_CARD: OK"));
    } else {
        Serial.println(F("SD_CARD: ERR"));
    }
    Serial.println(F("NANO_READY"));
}

// Returns true if the SD card is physically present and accessible
bool isCardPresent() {
    // Attempt to initialise the card (forces fresh SPI communication)
    if (SD.begin(SD_CS)) {
        return true;
    }
    return false;
}

void checkSDCard() {
    if (isWriting) return;
    if (millis() - lastCheck < CHECK_INTERVAL) return;
    lastCheck = millis();
    
    bool present = isCardPresent();
    
    if (present) {
        if (!sdReady) {
            // Card was absent, now present – need two consecutive successes
            successCounter++;
            if (successCounter >= 2) {
                sdReady = true;
                lastReportedState = true;
                digitalWrite(LED_BLUE, HIGH);
                Serial.println("SD_READY");
                // Blink once to indicate reinsertion
                digitalWrite(LED_BLUE, LOW);
                delay(50);
                digitalWrite(LED_BLUE, HIGH);
                successCounter = 0;
                failCounter = 0;
            }
        } else {
            // Already ready – reset failure counter
            failCounter = 0;
        }
    } else {
        if (sdReady) {
            // Card was present, now missing – need three consecutive failures
            failCounter++;
            if (failCounter >= 3) {
                sdReady = false;
                lastReportedState = false;
                digitalWrite(LED_BLUE, LOW);
                Serial.println("SD_FAIL");
                failCounter = 0;
                successCounter = 0;
            }
        } else {
            // Already failed – reset success counter
            successCounter = 0;
        }
    }
}

void acknowledgeWrite(bool success) {
    if (success) {
        Serial.println("SD_WRITE_OK");
        if (!sdReady) {
            // A successful write implies the card is ready
            failCounter = 0;
            successCounter = 1;   // next check will confirm
        }
    } else {
        Serial.println("SD_WRITE_ERR");
        if (sdReady) {
            // Immediate failure on write error
            sdReady = false;
            lastReportedState = false;
            digitalWrite(LED_BLUE, LOW);
            Serial.println("SD_FAIL");
            failCounter = 0;
            successCounter = 0;
        }
    }
}

void printTableTo(Print &p, int lpSize, int pktNum, float t, float h, float pr, float al, float lt, float lg, float ax, float ay, float az) {
    p.println(F("\n+------------------------------------------------------------------------------+"));
    p.println(F("|                    GROUND STATION SAVE TELEMETRY TABLE                       |"));
    p.println(F("+----------------------+---------------------------+---------------------------+"));
    p.println(F("| SENSOR               | PARAMETER                 | VALUE                     |"));
    p.println(F("+----------------------+---------------------------+---------------------------+"));
    p.print(F("| DHT22                | Temperature               | ")); p.print(t); p.println(F("C                    |")); 
    p.print(F("| DHT22                | Humidity                  | ")); p.print(h); p.println(F("%                    |")); 
    p.println(F("+----------------------+---------------------------+---------------------------+"));
    p.print(F("| BMP180               | Pressure                  | ")); p.print(pr, 0); p.println(F("Pa                   |")); 
    p.print(F("| BMP180               | Altitude (Est)            | ")); p.print(al); p.println(F("m                   |")); 
    p.println(F("+----------------------+---------------------------+---------------------------+"));
    p.print(F("| MPU6050              | Accel X/Y/Z               | ")); 
    p.print(ax, 1); p.print(", "); p.print(ay, 1); p.print(", "); p.print(az, 1); p.println(F("          |")); 
    p.println(F("+----------------------+---------------------------+---------------------------+"));
    if (lt != 0) { 
        p.print(F("| NEO-6M GPS           | Latitude                  | ")); p.println(lt, 6); 
        p.print(F("| NEO-6M GPS           | Longitude                 | ")); p.println(lg, 6); 
    } else { 
        p.println(F("| NEO-6M GPS           | Fix Status                | NO FIX / SEARCHING        |")); 
    } 
    p.println(F("+----------------------+---------------------------+---------------------------+"));
    p.println(F("| CONNECTION INFO      | PARAMETER                 | VALUE                     |"));
    p.println(F("+----------------------+---------------------------+---------------------------+"));
    p.print(F("| DX-LR03-LoRa         | Last Packet Size          | ")); p.print(lpSize); p.println(F("Bytes                   |")); 
    p.print(F("| DX-LR03-LoRa         | Packet Number             | ")); p.print(pktNum); p.println(F("Bytes                   |")); 
    p.println(F("+----------------------+---------------------------+---------------------------+"));
}
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
